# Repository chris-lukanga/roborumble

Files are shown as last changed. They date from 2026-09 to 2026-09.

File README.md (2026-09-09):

# Lightning McQueen 

**Team Name:** CO Coders
**Solution Name:** Lightning McQueen
**Category:** Robo Grand Prix (autonomous racing)
**Event:** Robo Rumble 2026 — Elimination Round

---

## What we are building

Lightning McQueen is an **autonomous line-following racer**. It reads the track
with a five-channel infrared reflective array, works out how far it is off the
line, and steers by commanding a **path curvature** rather than a raw motor
difference. The speed it runs at is then chosen from that curvature — flat out on
the straights, backed off exactly as much as the corner requires and no more.

There is no radio, no Wi-Fi and no Bluetooth anywhere on this vehicle. The only
human input is an ARM button pressed before the car is released, and the
emergency stop. That is a deliberate design decision, not an omission: Robo
Grand Prix requires full autonomy, and any human intervention forfeits the run.

**The strategy in one line:** most line followers lose time because they brake
for corners they have already entered. We compute the curvature the controller
is *about* to demand, and set the speed from that — so the car is already at the
right speed when the corner arrives.

---

## How we are building it

| Phase | Tool | Status |
|---|---|---|
| Control-law development | **Webots** (e-puck differential-drive model) | Complete — see `Folder B/Simulation` |
| Circuit design and MCU logic | **Wokwi** | Complete — see `Folder B/Schematics` |
| Mechanical design | **CadQuery** parametric CAD (OpenCASCADE kernel) | Complete — see `Folder B/Mechanical Design` |
| Physical build | Laser-cut acrylic deck, bolted assembly | Documented, not yet assembled |

Everything in this repository is reproducible. The CAD is a Python script, the
schematics are a Python script, the flowcharts are Mermaid source. Run them and
you get the same files back.

---

## Competition compliance

| Universal Design Constraint | How Lightning McQueen meets it |
|---|---|
| **1. Footprint ≤ 50 × 50 cm** | Overall envelope **300 × 211 × 107 mm**. The CAD build script asserts this on every run and fails loudly if a change ever breaks it. |
| **2. Mass < 5 kg** | Estimated **0.86 kg** fully assembled. Full mass budget in `Folder C/Holistic_Build_Document.md`. |
| **3. Accessible ON/OFF switch** | **SW2**, an SPST rocker at the rear-left corner of the deck, clear of the wheels and the sensor boom. Drawn and annotated in `Folder B/Schematics/01_power_safety_chain.svg`. |
| **4. Emergency Stop** | **SW1**, a 22 mm latching mushroom head on a 48 mm mast at the rear centreline. Wired **first** in the battery positive line, upstream of SW2 and of the H-bridge. Drawn and annotated in the same schematic and rendered in `Folder B/Mechanical Design/renders/04_safety_annotated.png`. |
| **Robo Grand Prix: fully autonomous** | No radio, no Wi-Fi, no Bluetooth, no serial command path. Serial is output-only telemetry. |

The 20 × 30 cm breadboard-on-plate layout from our original concept is carried
through: the 830-point breadboard sits on a 300 × 200 mm laser-cut acrylic deck
that also carries the Arduino, the H-bridge and the battery pack. Light materials
keep mass off the wheels; the batteries are the heaviest single item, which is
why we run **two 9 V PP3 cells** rather than twelve 1.5 V cells.

---

## Directory map

### [`Folder A — Source Code`](./Folder%20A)

Everything needed to run the build, plus the documentation of *how* the software
is put together.

| Path | Contents |
|---|---|
| `firmware/lightning_mcqueen/` | The race firmware. `lightning_mcqueen.ino` is the 200 Hz control superloop and five-state supervisor; `config.h` holds every tunable, each traceable to a datasheet, the CAD model, or a simulation sweep. |
| `firmware/calibration/` | A separate sketch that measures the sensor thresholds, the motor trim and the PWM deadband on the actual track, and prints the numbers to paste into `config.h`. |
| `simulation/` | The Webots C++ controller the control law was developed in. |
| `flowcharts/` | Five diagrams — system architecture, the control loop, the state machine, line-loss recovery, and the power/safety chain — as Mermaid source and rendered PNG. |
| `PROGRAMMING.md` | The programming methods, frameworks and architecture, with the flowcharts inline and the control law derived from first principles. |

### [`Folder B — Designs`](./Folder%20B)

The physical and electronic blueprints.

| Path | Contents |
|---|---|
| `Mechanical Design/` | `MECHANICAL_DESIGN.md` (fabrication method, fastening, mass budget), `CAD/` (the parametric model, STEP and STL for every part, a laser-cut DXF of the deck), `renders/` (five shaded views including the annotated safety view). |
| `Electronic Design/` | `ELECTRONIC_DESIGN.md` — why each sensor, driver and controller was chosen, with the alternatives we rejected and the reason. |
| `Schematics/` | `SCHEMATICS.md`, the full system schematic, and a dedicated power-and-safety-chain drawing with the ON/OFF switch and E-Stop explicitly annotated. Both are generated by `draw_schematics.py`. |
| `Simulation/` | `SIMULATION.md` — what we tested in Webots, what the sweeps told us, and which firmware constants came out of them. |

### [`Folder C — Documentation`](./Folder%20C)

| Path | Contents |
|---|---|
| `Pitch_Deck.pdf` | 7 slides: introduction, solution, technical approach, cost, team. |
| `Bill_of_Materials.xlsx` | Every component with quantity, unit cost, supplier, stock code and buy link. **Total cost is highlighted in red.** |
| `Holistic_Build_Document.md` | The full written report: constraints, solution, BOM summary, and the three required technical sub-sections (mechanical, electronic, programming). |
| `FQA_Attendance_Log.md` | Facilitator Q&A attendance logbook. |
| `FQA_Proof/` | Attendance screenshots referenced by the logbook. |

---

## Reproducing the design files

```bash
pip install cadquery schemdraw matplotlib numpy

# CAD: STEP + STL for every part, plus the laser-cut DXF
python3 "Folder B/Mechanical Design/CAD/lightning_mcqueen_cad.py"

# Renders: five shaded views
python3 "Folder B/Mechanical Design/CAD/render_views.py"

# Schematics: SVG + PNG
python3 "Folder B/Schematics/draw_schematics.py"
```

---

## Team

| Member | Role |
|---|---|
| *(see `Folder C/Pitch_Deck.pdf`, Team Slide)* | |

---

## Credits and attribution

- The Webots control law began from the standard e-puck line-following example
  distributed with Webots, and was rewritten around curvature control and a
  speed schedule. The original example's structure is acknowledged.
- The TCRT5000 sensing approach follows the device datasheet's recommended
  8–15 mm standoff.
- Everything else — the firmware, the CAD, the schematics and the documentation
  in this repository — is our own work.

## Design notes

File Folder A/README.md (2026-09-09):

# Folder A — Source Code

All programming scripts, firmware and code required to run Lightning McQueen,
plus the documentation of the programming methods, frameworks and design.

**Start here:** [`PROGRAMMING.md`](PROGRAMMING.md) — the frameworks we use, the
control law derived from first principles, and all five flowcharts.

| Path | What it is |
|---|---|
| [`PROGRAMMING.md`](PROGRAMMING.md) | Programming methods, frameworks, architecture and flowcharts |
| [`firmware/lightning_mcqueen/`](firmware/lightning_mcqueen) | The race firmware — 200 Hz control superloop and five-state supervisor |
| [`firmware/lightning_mcqueen/config.h`](firmware/lightning_mcqueen/config.h) | Every tunable in one place, each traceable to a datasheet, the CAD model or a simulation sweep |
| [`firmware/calibration/`](firmware/calibration) | Measures sensor thresholds, motor trim and PWM deadband on the real track |
| [`simulation/`](simulation) | The Webots C++ controller the control law was developed in |
| [`flowcharts/`](flowcharts) | Five diagrams as Mermaid source (`.mmd`) and rendered PNG |

## Building and flashing

```
Arduino IDE 2.x  →  Board: Arduino Uno  →  Port: your Uno
Open  firmware/lightning_mcqueen/lightning_mcqueen.ino  →  Upload
```

`config.h` must sit in the same folder as the `.ino` — the Arduino IDE requires
the sketch folder name to match the sketch name, which is why the structure
looks the way it does.

**Order of operations on a new car:**

1. Flash `firmware/calibration/calibration.ino`.
2. Send `1` over serial at 115200 and sweep the car across the line for 10 s.
   Paste the printed `SENSOR_MIN[]` / `SENSOR_MAX[]` arrays into `config.h`.
3. Send `3` and note the duty at which each wheel first turns. That is
   `PWM_DEADBAND`.
4. Send `2` and measure the travel of each wheel. That ratio is `TRIM_RIGHT`.
5. Flash `firmware/lightning_mcqueen/lightning_mcqueen.ino`.

## Category alignment

This is autonomous racing code and nothing else. No radio, no Wi-Fi, no
Bluetooth, no serial command path — `Serial` is written to and never read. The
only human input is the ARM button pressed before the car is released.

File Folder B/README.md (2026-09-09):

# Folder B — Designs

The physical and electronic blueprints for Lightning McQueen.

| Subfolder | Start here | Contents |
|---|---|---|
| [`Mechanical Design/`](Mechanical%20Design) | [`MECHANICAL_DESIGN.md`](Mechanical%20Design/MECHANICAL_DESIGN.md) | Fabrication method, fastening scheme, mass budget, parametric CAD (STEP/STL/DXF) and five shaded renders |
| [`Electronic Design/`](Electronic%20Design) | [`ELECTRONIC_DESIGN.md`](Electronic%20Design/ELECTRONIC_DESIGN.md) | Justification for every sensor, driver and control unit, with the alternatives we rejected and why |
| [`Schematics/`](Schematics) | [`SCHEMATICS.md`](Schematics/SCHEMATICS.md) | Full system schematic plus a dedicated power-and-safety-chain drawing with the ON/OFF switch and E-Stop annotated |
| [`Simulation/`](Simulation) | [`SIMULATION.md`](Simulation/SIMULATION.md) | What we tested in Webots, what the sweeps told us, which constants came out of them, and what simulation could not tell us |

## Safety compliance at a glance

| Constraint | Where it is drawn | Where it is rendered |
|---|---|---|
| **3 — accessible ON/OFF switch** | [`Schematics/01_power_safety_chain.svg`](Schematics/01_power_safety_chain.svg) — SW2, annotated | [`Mechanical Design/renders/04_safety_annotated.png`](Mechanical%20Design/renders/04_safety_annotated.png) |
| **4 — Emergency Stop** | [`Schematics/01_power_safety_chain.svg`](Schematics/01_power_safety_chain.svg) — SW1, annotated, first in the battery positive line | [`Mechanical Design/renders/04_safety_annotated.png`](Mechanical%20Design/renders/04_safety_annotated.png) |

## Everything here is reproducible

```bash
pip install cadquery schemdraw matplotlib numpy

python3 "Mechanical Design/CAD/lightning_mcqueen_cad.py"   # STEP, STL, DXF
python3 "Mechanical Design/CAD/render_views.py"            # the five renders
python3 "Schematics/draw_schematics.py"                    # both schematics
```

The CAD build script asserts the 50 × 50 cm footprint rule on every run and
fails loudly if a parameter change ever breaks it.

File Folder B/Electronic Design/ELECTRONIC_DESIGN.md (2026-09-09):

# Electronic Design

**Team CO Coders · Lightning McQueen · Robo Rumble 2026 · Robo Grand Prix**

This document justifies every active component on the vehicle. For each one we
state what it does, why it was chosen, and what we rejected instead. The wiring
itself is in [`../Schematics`](../Schematics).

---

## 1. Control unit — Arduino Uno R3 (ATmega328P)

**Role.** Reads five analog channels, runs the control law at 200 Hz, drives six
pins into the H-bridge.

**Why.** The job is small and the requirements are specific: at least five ADC
channels, two independent hardware PWM timers, and enough determinism to trust a
5 ms loop. The ATmega328P has six ADC channels and three timers, and its
successive-approximation ADC converts in 104 µs. Five conversions cost 520 µs —
10 % of the control period. The whole pipeline measures ~760 µs, so we run at
15 % CPU with 85 % headroom.

**Why not an ESP32.** It is faster, it has more ADC resolution, and we
considered it seriously. Two things ruled it out. First, its ADC is
non-linear near the rails and needs per-channel characterisation to be trusted —
extra work for a signal we are already normalising. Second, and decisively, it
arrives with Wi-Fi and Bluetooth radios on the die. Robo Grand Prix forbids
remote control of any kind. We would rather hand a judge a board that
*physically cannot* be commanded remotely than a board where the argument
depends on firmware we claim we did not write.

**Why not a bare ATmega328P on the breadboard.** It saves 15 g and R120, and
costs an afternoon of bootloader and crystal work at the point in the schedule
where we can least afford it.

**Pin map and the one non-obvious decision.**

| Function | Pin | Note |
|---|---|---|
| Sensor channels 1–5 | A0–A4 | A5 left free for a future encoder or I²C |
| Motor A direction | D2, D4 | plain digital |
| Motor A speed | **D9** | Timer1 |
| Motor B direction | D7, D8 | plain digital |
| Motor B speed | **D10** | Timer1 |
| ARM button | D12 | `INPUT_PULLUP`, active low |
| Status LED | D13 | on-board LED doubles as the status light |
| Buzzer | D3 | Timer2 via `tone()` |

The PWM pins are on **Timer1 (D9, D10), not Timer0 (D5, D6)**. Timer0 drives
`millis()` and `micros()`, which the fixed-rate scheduler depends on. Sharing it
with motor PWM is the kind of coupling that produces a bug you only see at one
particular duty cycle, three days before the event.

---

## 2. Motor driver — L298N dual H-bridge module

**Role.** Takes 9 V from the switched battery rail and six logic lines from the
Uno, and drives two motors bidirectionally. Its on-board 78M05 also generates
the 5 V logic rail.

**Why.** It handles 2 A per channel against a stall current of roughly 1.2 A per
TT motor, so there is real margin. The module carries flyback diodes and the
regulator already, which removes a whole subcircuit from the breadboard — and a
breadboard is exactly where a hand-wired flyback diode goes intermittent.

**The honest downside.** The L298 is a bipolar bridge and drops roughly 1.9 V
across itself. From a 9 V pack, the motors see about 7.1 V, and the wheels do
not turn at all below about 16 % duty. We handle this in two places:

- `PWM_DEADBAND = 42` in `config.h` maps the controller's 0–1 output onto duty
  42–255, so a small correction actually produces movement instead of only
  heating the bridge;
- the calibration sketch (mode 3) measures the real deadband on the actual
  motors, because it varies between gearboxes.

**Why not a TB6612FNG.** It is a MOSFET bridge, drops ~0.5 V instead of 1.9 V,
and is genuinely the better part — we would gain roughly 18 % top speed. It was
rejected on availability and cost risk: the L298N is stocked by every South
African hobby supplier and costs a third as much. If a TB6612FNG is in hand
before the build, it is a drop-in swap: same six control lines, same pin map,
and only `PWM_DEADBAND` and `MAX_WHEEL_RPM` change.

---

## 3. Sensing — 5-channel TCRT5000 reflective array

**Role.** Measures how far the car is off the line.

**Why this sensor.** The TCRT5000 is an IR emitter and phototransistor in one
package with a daylight-blocking filter over the detector. Its datasheet optimum
standoff is 8–15 mm; we mount at 12 mm, in the middle of that band, so ±3 mm of
deck deflection or track unevenness does not move us out of it.

**Why five channels and not three.** This is the single most consequential
electronic decision on the car.

Three binary sensors can only report five distinct error values:
{−1, −0.5, 0, +0.5, +1}. That is what our Webots prototype had, and the
quantisation is why its derivative term needed such heavy filtering — every
transition was a step change. Five **analog** channels let us compute a weighted
centroid, which is continuous. Continuous error means:

- the derivative term is usable, so the car damps its own oscillation instead of
  weaving down the straights;
- the speed schedule sees corner entry developing gradually rather than as a
  step, so it sheds speed smoothly instead of lurching;
- a 40 mm sensing span at 20 mm pitch straddles a 19 mm competition line with a
  channel to spare on each side, so a moderate excursion is still measured
  rather than simply "lost".

The cost of the two extra channels is about R40 and two ADC pins we had spare.

**Per-channel calibration.** The five devices differ measurably in LED output
and phototransistor gain. `config.h` therefore stores `SENSOR_MIN[]` and
`SENSOR_MAX[]` per channel rather than one global threshold, and
`calibration.ino` mode 1 measures them on the actual track under the actual
lighting. It also warns if any channel shows less than 350 counts of
floor-to-line contrast, which is the signal that the ride height or the trim pot
is wrong — better to find that in the pit than on the grid.

---

## 4. Power — 2 × 9 V PP3

**Role.** One switched 9 V rail feeding the H-bridge, from which the 78M05
derives 5 V logic.

**Why 9 V PP3 and not AA cells.** Our concept notes committed to this and the
mass budget vindicates it: two PP3 cells weigh 92 g where twelve 1.5 V AA cells
weigh about 276 g. On a car whose whole assembled mass is 855 g, that is a
21 % difference in the load the same TT gearboxes have to accelerate.

**The honest downside.** A PP3 alkaline has roughly 550 mAh and a fairly high
internal resistance. Two in series-parallel give us about 1.2 Ah at 9 V, which is
comfortable for a race heat but not for an afternoon of testing — and under a
stall the terminal voltage sags enough to matter. Mitigations:

- the polyfuse and the wiring are sized for the sag, not the nominal;
- `TRIM_RIGHT` and the speed schedule are calibrated on a fresh pack, and the
  pack is swapped between heats (hook-and-loop straps, ten seconds);
- for bench testing we run from a 9 V bench supply, not from cells.

**Single rail, not two.** Some designs run separate logic and motor batteries so
that motor sag cannot brown out the MCU. We deliberately do not, because a
separate logic battery would keep the MCU alive after the E-Stop opens the motor
rail. A shared rail means one switch kills everything — which is exactly what
Universal Design Constraint 4 asks for. The trade is a 100 µF bulk capacitor on
the 5 V rail to ride out switching transients.

---

## 5. Protection and indication

| Part | Value | Why |
|---|---|---|
| **F1** polyfuse | 2 A hold | Against a stalled motor or a wiring short. Resettable, so a pit incident does not consume a spare. Sized above the 1.2 A per-motor stall so it does not nuisance-trip on a hard corner. |
| **D1** power LED | + 1 kΩ | Shows the rail is live. On a car whose normal state is "sitting still, waiting", this is the difference between a safe approach and an assumed-dead robot. |
| **D2** status LED | on-board D13, 220 Ω | Blink codes state: slow = disarmed, fast = armed countdown, solid = racing, urgent = fault. Readable from the side of the track. |
| **LS1** piezo | on D3 | Audible arm, countdown and fault. A marshal facing away still hears the fault tone. |
| **C1** bulk cap | 100 µF on the 5 V rail | Rides out H-bridge switching transients. Deliberately no larger — see the safety note below. |

**A note on that capacitor.** 100 µF at 5 V stores 1.25 mJ. A loaded TT gearbox
needs on the order of a joule to turn once. There is no combination of
downstream capacitance on this vehicle that could move a wheel after the E-Stop
opens, and that is a design constraint we checked rather than assumed.

---

## 6. Safety devices — Universal Design Constraints 3 and 4

Detailed in [`../Schematics/SCHEMATICS.md`](../Schematics/SCHEMATICS.md) and
drawn in `../Schematics/01_power_safety_chain.svg`. In summary:

- **SW1, E-Stop:** 22 mm latching mushroom, normally closed, **first device in
  the battery positive line**, upstream of SW2 and of the L298N.
- **SW2, ON/OFF:** SPST rocker, second in the same line.

Because the 5 V logic rail is derived downstream of both, opening either one
de-energises the MCU, the sensor array and the motors together. No firmware path
can defeat SW1, because the contact is mechanically in the battery line.

---

## 7. Component summary

| Ref | Component | Qty | Function |
|---|---|---:|---|
| U1 | L298N dual H-bridge module | 1 | Motor drive + 5 V regulation |
| U2 | Arduino Uno R3 | 1 | Control |
| U3 | 5-channel TCRT5000 array | 1 | Line sensing |
| M1, M2 | TT gear motor 1:48 + 65 mm wheel | 2 | Drive |
| BT1, BT2 | 9 V PP3 + holder | 2 | Power |
| SW1 | 22 mm latching E-Stop, NC | 1 | **Emergency stop (Constraint 4)** |
| SW2 | SPST rocker switch | 1 | **ON/OFF (Constraint 3)** |
| SW3 | Momentary pushbutton | 1 | ARM |
| F1 | 2 A resettable polyfuse | 1 | Overcurrent protection |
| D1 | 5 mm LED + 1 kΩ | 1 | Power-on indication |
| D2 | Status LED + 220 Ω | 1 | State indication |
| LS1 | Piezo buzzer | 1 | Audible state |
| C1 | 100 µF electrolytic | 1 | 5 V rail bulk |
| — | 830-point breadboard | 1 | Interconnect |
| — | Ball castor, 20 mm | 1 | Tail support |

Costs, suppliers, stock codes and buy links are in
[`../../Folder C/Bill_of_Materials.xlsx`](../../Folder%20C/Bill_of_Materials.xlsx).

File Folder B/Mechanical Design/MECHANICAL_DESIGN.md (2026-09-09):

# Mechanical Design

**Team CO Coders · Lightning McQueen · Robo Rumble 2026 · Robo Grand Prix**

---

## 1. The design at a glance

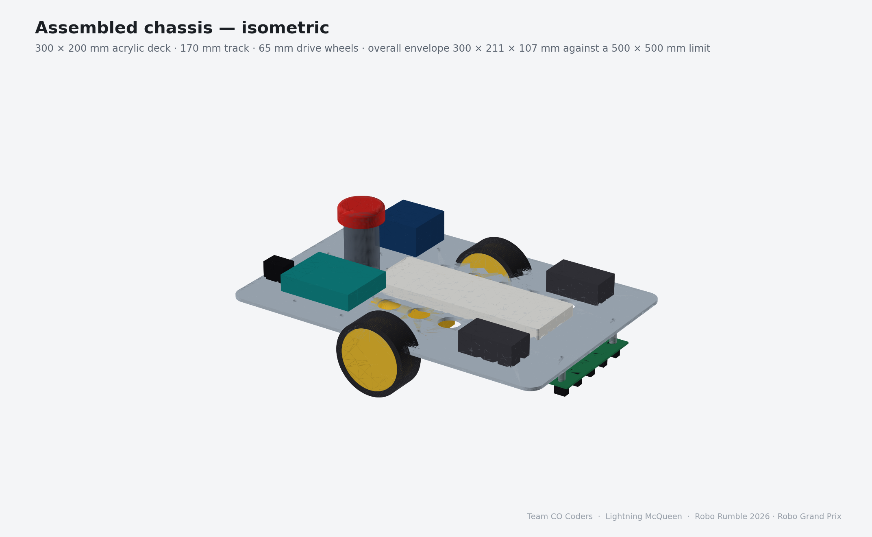
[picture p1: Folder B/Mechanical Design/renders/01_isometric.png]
Assembled chassis


A single 3 mm laser-cut acrylic deck, 300 × 200 mm, carrying everything. The
830-point breadboard sits on top on the centreline; the Arduino and the L298N
flank it; the battery pack sits forward. Two TT gear motors bolt through the
deck from below at mid-wheelbase, a ball castor supports the tail, and the
sensor boom hangs off the nose on nylon standoffs.

| | |
|---|---|
| Overall envelope | **300 × 211 × 107 mm** (limit: 500 × 500 mm) |
| Deck | 300 × 200 × 3 mm cast acrylic |
| Track (wheel centres) | 170 mm |
| Wheelbase (axle to castor) | 118 mm |
| Ground clearance under the deck | 42 mm |
| Sensor ride height | 12 mm above the floor |
| Sensor lead ahead of the drive axle | 138 mm |
| Estimated assembled mass | **0.86 kg** (limit: below 5 kg) |

The width comes out at 211 mm rather than 200 mm because the wheels sit 5.5 mm
proud of the deck on each side. That is intentional: it keeps the tyres clear of
the deck edge so a brush against a barrier hits rubber, not acrylic.

---

## 2. Fabrication method

**The deck is laser cut, not drilled.** `CAD/deck_plate_laser_cut.dxf` is a 1:1
flat profile containing the outline, all 34 M3 clearance holes, the 22.5 mm
E-Stop bore, the lightening holes and the two cable slots. It goes to the cutter
as-is. Nothing on this vehicle is marked out and drilled by hand, because
hand-drilled acrylic chips and hand-marked hole patterns do not repeat.

| Part | Method | Material |
|---|---|---|
| Deck plate | Laser cut from the supplied DXF | 3 mm cast acrylic |
| E-Stop mast | 3D printed, 30 mm dia × 48 mm, 4 perimeters, 40 % infill | PLA |
| Sensor boom standoffs | Off-the-shelf | M3 × 30 mm nylon hex standoffs |
| Deck module standoffs | Off-the-shelf | M3 × 8 mm nylon hex standoffs |
| Motor brackets | Off-the-shelf, supplied with the TT motors | ABS |
| Fasteners throughout | Off-the-shelf | M3 × 10 mm pan-head, nyloc nuts |

**Why acrylic rather than 3D printing the whole chassis.** A printed monocoque
looks better in renders, but a 300 mm printed part warps, takes eight hours, and
cannot be re-cut in an afternoon when a mounting hole turns out to be 4 mm out.
A laser-cut flat plate takes ninety seconds on the machine and is dimensionally
exact. For a competition where the schedule is the real constraint, that matters
more than the aesthetics.

**Why 3 mm and not 5 mm.** 3 mm cast acrylic spanning 300 mm with the load
concentrated at the motor mounts deflects about 0.4 mm at the nose under the
assembled mass — well inside the ±2 mm the sensor ride height tolerates. Going to
5 mm would add 240 g for stiffness we do not need.

---

## 3. Fastening and assembly

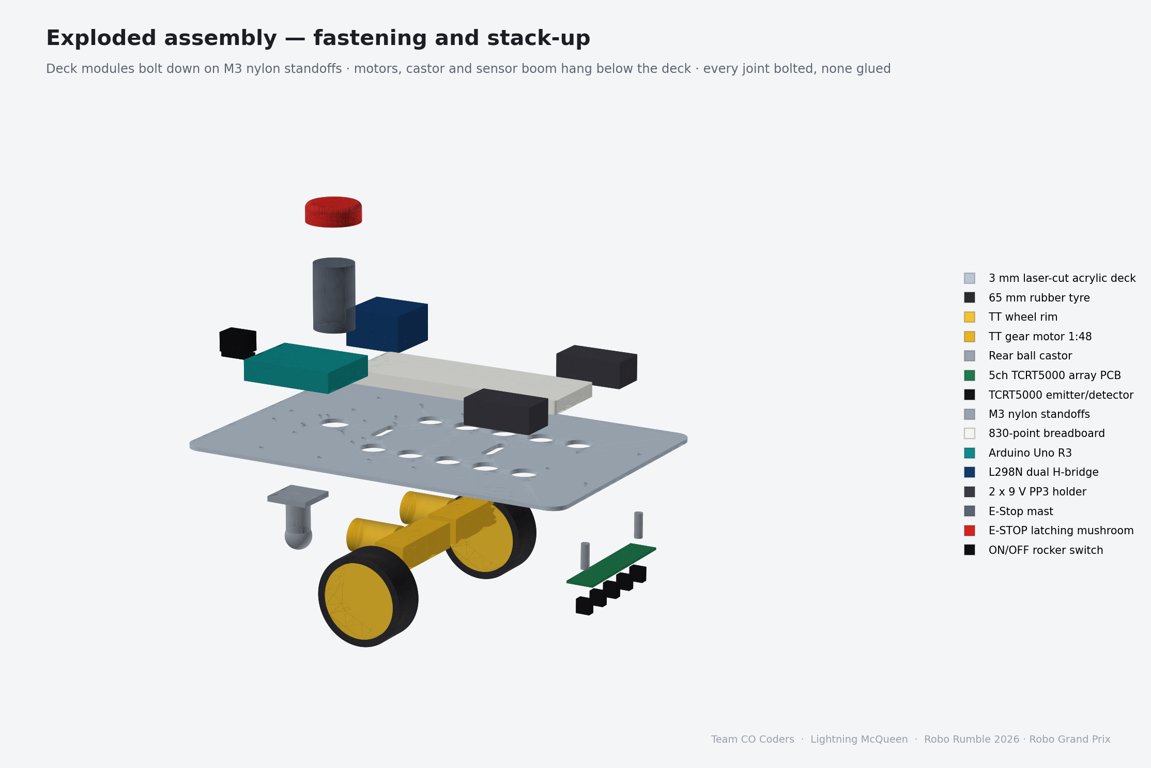
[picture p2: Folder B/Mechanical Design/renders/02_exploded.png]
Exploded assembly


**Every joint on this vehicle is bolted. Nothing is glued.** Adhesive joints in
acrylic are brittle, they cannot be adjusted, and when a sensor turns out to be
2 mm too low there is no way back. Bolted joints come apart.

The stack-up, from the ground up:

1. **Wheels** press onto the TT motor D-shafts.
2. **TT motors** bolt to the underside of the deck through the ABS brackets,
   two M3 per side, at X = 150 mm from the tail.
3. **Ball castor** bolts to the underside at the tail on a 24 mm square M3
   pattern.
4. **Sensor boom** hangs on two M3 × 30 mm nylon standoffs at X = 288 mm,
   ±40 mm either side of the centreline. Nylon, not steel, because the standoffs
   sit directly beside the IR emitters and a steel post reflects.
5. **Breadboard** sits on the deck centreline on 8 mm standoffs, four M3.
6. **Arduino Uno** and **L298N** bolt down on 8 mm standoffs on either flank,
   four M3 each.
7. **Battery holders** are strapped forward with hook-and-loop, so a flat pack
   is a ten-second swap between heats rather than an unbolting job.
8. **E-Stop mast** bolts down on a 4 × M3 circle on a 22 mm radius, over the
   22.5 mm bore that passes the button body through the deck.

### Adjustment designed in

- **Sensor ride height** is set by the standoff length. If the track surface
  reads badly at 12 mm, an M3 × 25 or M3 × 35 standoff moves it without
  re-cutting anything.
- **Weight distribution** is set by where the battery straps sit. Moving the
  pack rearward shifts load onto the drive wheels for grip; forward reduces
  castor scrub.
- **Motor position** is fixed. This is the one dimension we do not want anyone
  adjusting between heats — it sets the sensor lead, which the speed schedule
  depends on.

---

## 4. Underside — drivetrain and sensing

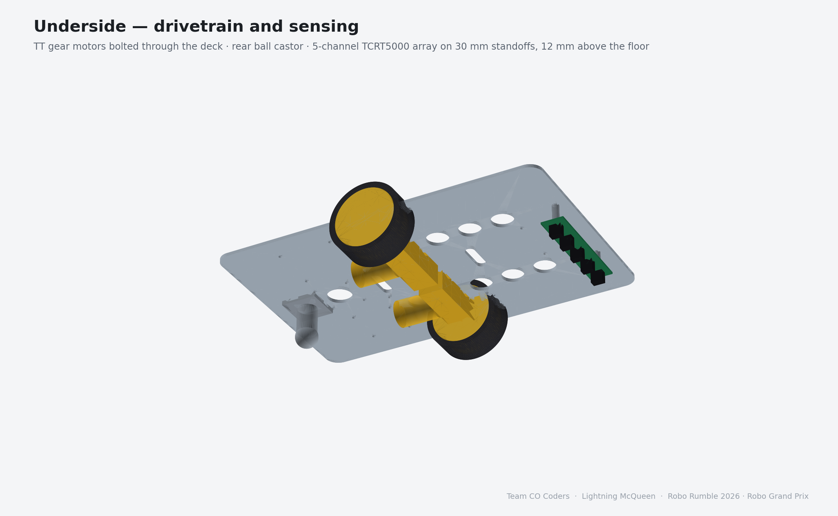
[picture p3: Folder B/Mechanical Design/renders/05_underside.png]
Underside


The two TT gearboxes point inboard from the wheels and very nearly meet on the
centreline, which is the standard dual-TT arrangement and keeps the mass low and
central. The castor carries perhaps 15 % of the mass; the rest sits over the
drive wheels, which is where it is useful.

The sensor boom is the part most likely to be damaged, so it is the part that is
easiest to replace: two standoffs, two bolts, and it is off.

---

## 5. Safety hardware — Universal Design Constraints 3 and 4

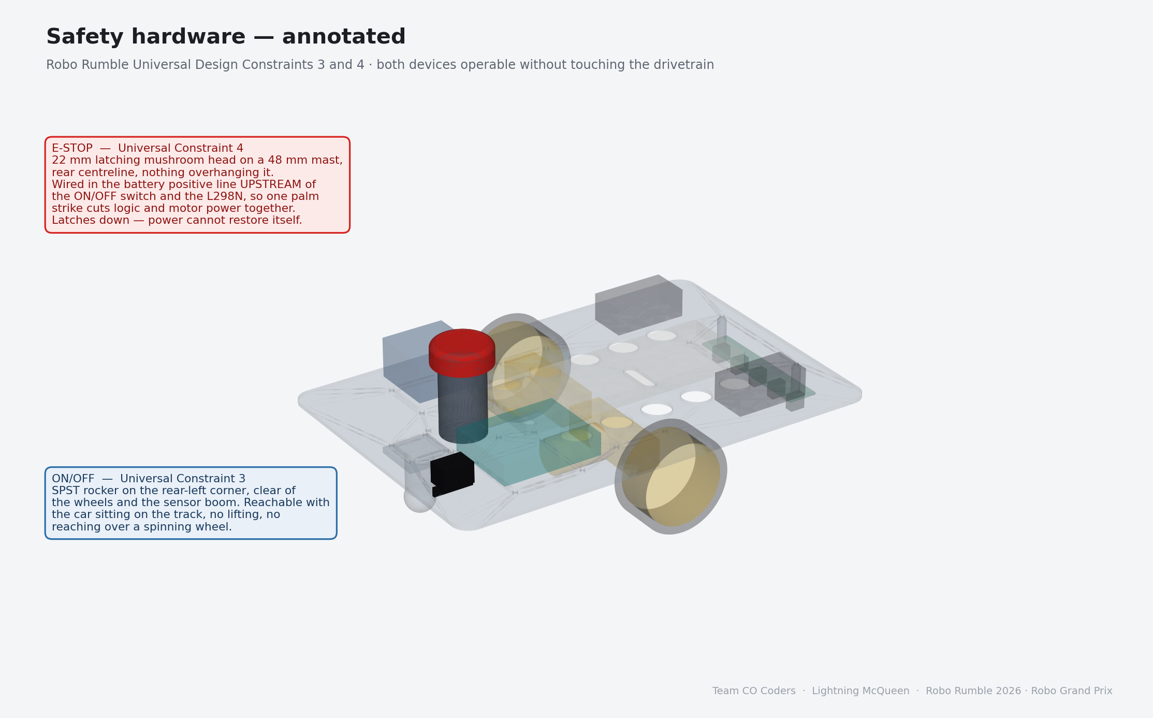
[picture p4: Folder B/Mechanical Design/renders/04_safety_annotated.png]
Safety hardware annotated


**E-Stop (Constraint 4).** A 22 mm latching mushroom head on a 48 mm printed
mast at the rear centreline. It is the tallest object on the car and nothing
overhangs it, so it can be struck from above or from behind with an open palm
while the car is moving. It latches down: power cannot restore itself until an
operator twists the head back out. Electrically it is the *first* device in the
battery positive line — see `../Schematics/01_power_safety_chain.svg`.

**ON/OFF (Constraint 3).** An SPST rocker at the rear-left corner of the deck,
clear of the wheels and of the sensor boom. It is operable with the car sitting
on the grid — no lifting, no tilting, and no reaching across a wheel that is
about to spin.

Both are at the rear because that is the end an operator approaches from. The
E-Stop is on the centreline and raised; the ON/OFF is in the corner and flush.
They are not confusable by feel.

---

## 6. Orthographic views

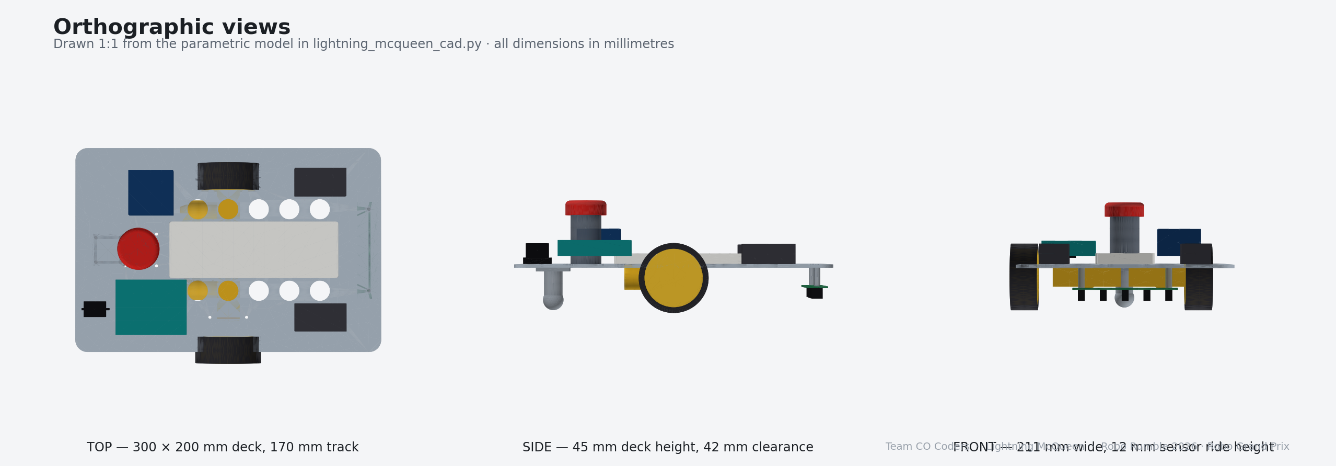
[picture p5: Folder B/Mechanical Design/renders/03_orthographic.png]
Orthographic views


Drawn 1:1 from the parametric model.

---

## 7. Mass budget

| Item | Qty | Unit (g) | Total (g) |
|---|---:|---:|---:|
| 3 mm acrylic deck, 300 × 200 mm, holed | 1 | 198 | 198 |
| TT gear motor 1:48 | 2 | 30 | 60 |
| 65 mm wheel | 2 | 30 | 60 |
| Ball castor assembly | 1 | 28 | 28 |
| Arduino Uno R3 | 1 | 25 | 25 |
| L298N module | 1 | 30 | 30 |
| 830-point breadboard | 1 | 90 | 90 |
| 5-channel TCRT5000 array | 1 | 12 | 12 |
| 9 V PP3 alkaline | 2 | 46 | 92 |
| Battery holders and straps | 2 | 14 | 28 |
| E-Stop button + printed mast | 1 | 62 | 62 |
| Rocker switch, fuse, LEDs, buzzer | — | — | 22 |
| Standoffs, bolts, nuts (≈60 pieces) | — | — | 68 |
| Wiring loom | — | — | 80 |
| **Total** | | | **855 g** |

**0.86 kg against a 5 kg limit.** We are at 17 % of the allowance, which is the
point of the light-material approach: less mass on the wheels means the same TT
gearboxes accelerate harder and the same tyres hold a tighter corner. The
batteries are the heaviest single line item at 92 g, which is exactly why two
9 V PP3 cells were chosen over twelve 1.5 V AA cells (≈276 g).

---

## 8. Files in this folder

```
Mechanical Design/
├── MECHANICAL_DESIGN.md              this document
├── CAD/
│   ├── lightning_mcqueen_cad.py      the parametric model — edit the
│   │                                 PARAMETERS block and re-run
│   ├── render_views.py               generates everything in renders/
│   ├── deck_plate_laser_cut.dxf      1:1 flat profile for the laser cutter
│   ├── lightning_mcqueen_assembly.step   full coloured assembly
│   ├── STEP/                         one .step per part (Fusion / SolidWorks)
│   └── STL/                          one .stl per part (printing, meshing)
└── renders/
    ├── 01_isometric.png
    ├── 02_exploded.png
    ├── 03_orthographic.png
    ├── 04_safety_annotated.png
    └── 05_underside.png
```

The model is parametric. Changing `TRACK` or `WHEEL_D` at the top of
`lightning_mcqueen_cad.py` and re-running regenerates every STEP, STL, the DXF
and all five renders consistently. The build script also asserts the 50 × 50 cm
footprint rule on every run and fails loudly if a change ever breaks it.

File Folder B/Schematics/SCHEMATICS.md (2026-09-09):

# Schematics

**Team CO Coders · Lightning McQueen · Robo Rumble 2026 · Robo Grand Prix**

Two drawings. The first is the safety-critical power path on its own, because
Universal Design Constraints 3 and 4 deserve a drawing where nothing competes
for attention. The second is the complete system.

Both are generated by `draw_schematics.py` — run it and you get identical files
back. SVG is the master; PNG is provided for the pitch deck and for readers
without an SVG viewer.

---

## 1. Power and safety chain — Constraints 3 and 4

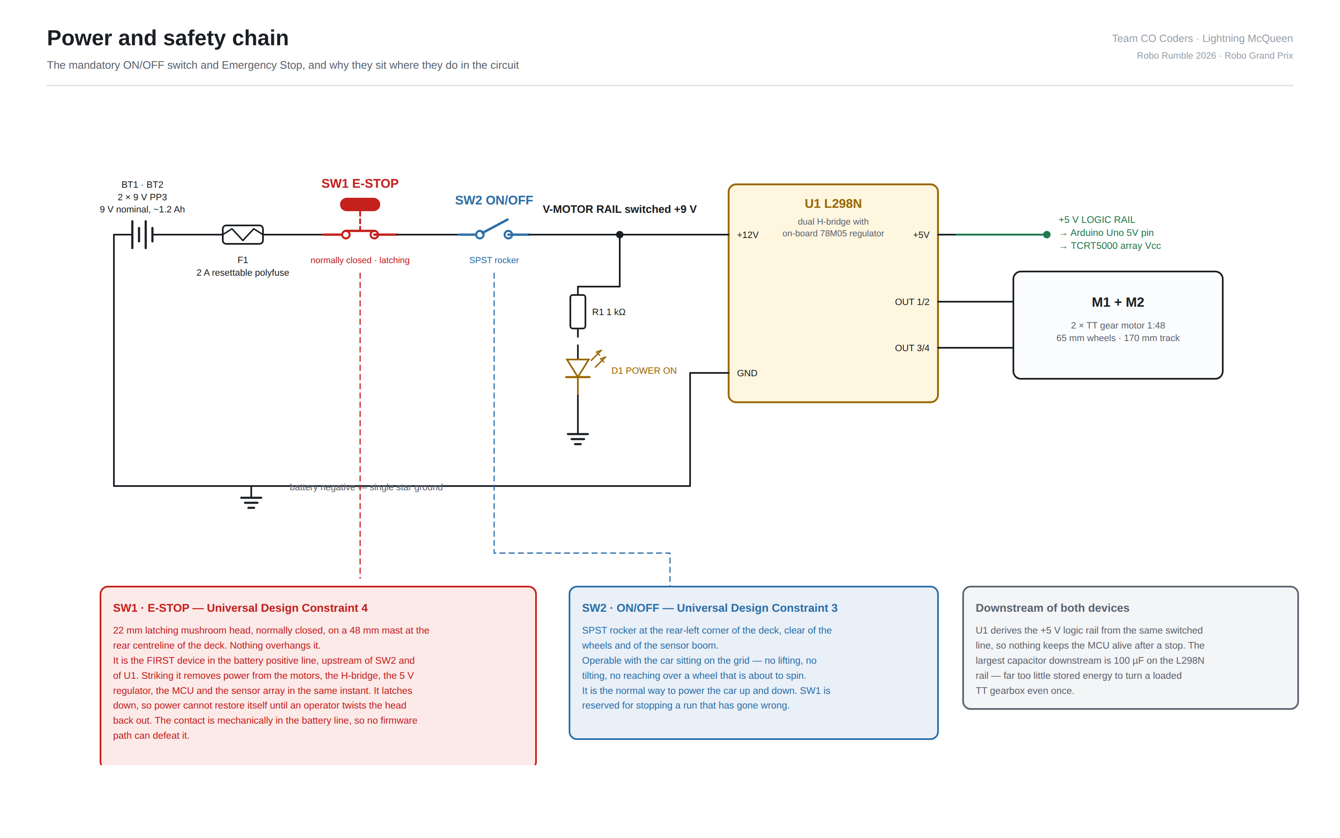
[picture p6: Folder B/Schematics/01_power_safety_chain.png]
Power and safety chain


### The chain, in order

```
BT1/BT2  →  F1  →  SW1 (E-STOP)  →  SW2 (ON/OFF)  →  U1 (L298N)  →  motors
2 × 9 V     2 A     latching NC       SPST rocker      +12V           M1, M2
                                                          ↓
                                                   78M05 → +5 V rail
                                                          ↓
                                              Arduino Uno · TCRT5000 array
```

### SW1 — Emergency Stop (Universal Design Constraint 4)

| | |
|---|---|
| Device | 22 mm latching mushroom-head pushbutton, **normally closed** |
| Location | Rear centreline of the deck, on a 48 mm mast — the tallest object on the car, nothing overhanging it |
| Position in circuit | **First device in the battery positive line**, upstream of SW2 and of U1 |
| Action | Struck from above or behind with an open palm. Latches down. |
| Reset | Twist the head to release — cannot restore itself |

**Why it is placed first.** Everything on this vehicle draws from one switched
rail. U1's on-board 78M05 derives the 5 V logic supply from the same line that
feeds the motors, so opening SW1 removes power from the motors, the H-bridge,
the regulator, the MCU and the sensor array **in the same instant**. There is no
sequencing, no software involvement and no state to unwind.

**Why it cannot be defeated.** The contact is mechanically in series with the
battery. No firmware path can bridge it, because there is no firmware left
running once it opens.

**Why residual energy is not a hazard.** The largest capacitor downstream is the
100 µF bulk cap on the 5 V rail, storing 1.25 mJ. Turning a loaded TT gearbox
through one revolution needs on the order of a joule — roughly a thousand times
more. The car cannot creep after a stop.

### SW2 — ON/OFF (Universal Design Constraint 3)

| | |
|---|---|
| Device | SPST rocker |
| Location | Rear-left corner of the deck, clear of the wheels and of the sensor boom |
| Position in circuit | Second in the battery positive line, immediately after SW1 |
| Access | Operable with the car sitting on the grid — no lifting, no tilting, no reaching across a wheel |

SW2 is the normal way to power the car up and down. SW1 is reserved for stopping
a run that has gone wrong. Placing them both at the rear — the end an operator
approaches from — with the E-Stop raised on the centreline and the rocker flush
in the corner means they are not confusable by feel.

---

## 2. Full system schematic

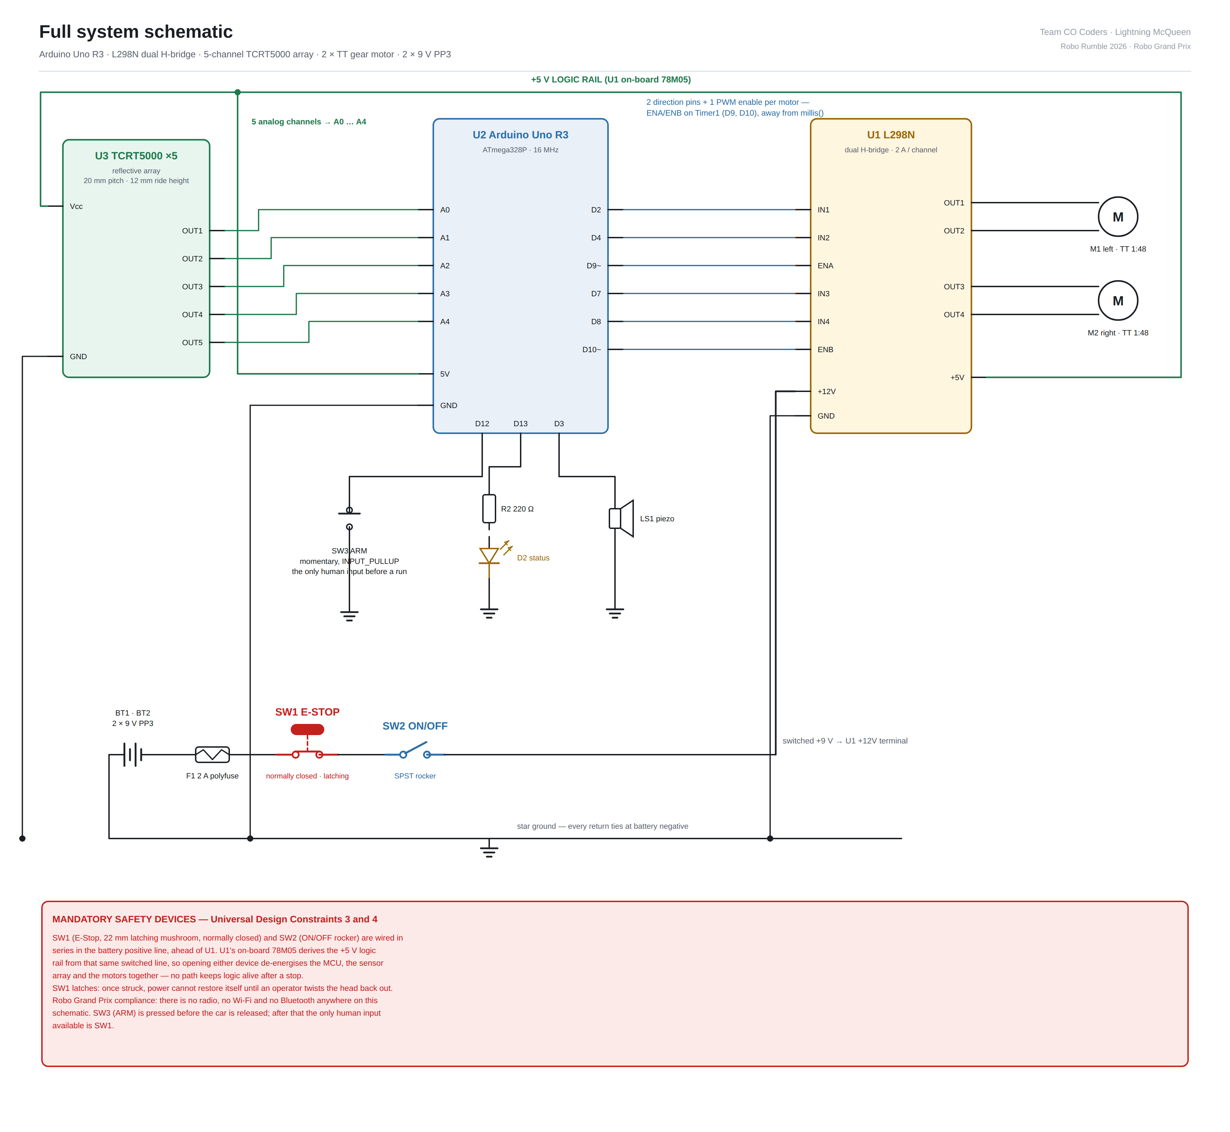
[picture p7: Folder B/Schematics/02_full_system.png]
Full system schematic


### Wiring table

| From | To | Signal |
|---|---|---|
| U3 OUT1 … OUT5 | U2 A0 … A4 | 5 analog sensor channels |
| U2 D2, D4 | U1 IN1, IN2 | Motor A direction |
| U2 D9 (Timer1) | U1 ENA | Motor A PWM |
| U2 D7, D8 | U1 IN3, IN4 | Motor B direction |
| U2 D10 (Timer1) | U1 ENB | Motor B PWM |
| U1 OUT1, OUT2 | M1 | Left motor |
| U1 OUT3, OUT4 | M2 | Right motor |
| U1 +5V | U2 5V, U3 Vcc | Derived logic rail |
| U2 D12 | SW3 → GND | ARM button, `INPUT_PULLUP` |
| U2 D13 | R2 220 Ω → D2 → GND | Status LED |
| U2 D3 | LS1 → GND | Piezo buzzer |
| BT1/BT2 + | F1 → SW1 → SW2 → U1 +12V | Switched battery positive |
| All GND | U1 GND pad | Star ground to battery negative |

### Grounding

Single star point at the L298N GND pad, which is the only tie to battery
negative. The sensor array, the Uno and the H-bridge each return there
independently rather than daisy-chaining, so motor current does not share a
conductor with the analog sensor return. On a car where the measurement is an
ADC reading of a phototransistor and the load is a pair of brushed motors, that
separation is what keeps the line position from wobbling every time the motors
change duty.

### Robo Grand Prix compliance, visible on the drawing

There is no radio, no Wi-Fi module, no Bluetooth module and no receiver anywhere
on this schematic. The only human-operable devices are SW1 (E-Stop), SW2
(ON/OFF) and SW3 (ARM, pressed before the car is released). Serial is used for
telemetry out and is never read.

---

## 3. Files

```
Schematics/
├── SCHEMATICS.md                  this document
├── draw_schematics.py             generates both drawings
├── 01_power_safety_chain.svg/.png Constraints 3 and 4, annotated
└── 02_full_system.svg/.png        complete wiring
```

Regenerate with:

```bash
pip install matplotlib          # not required for the SVG, only for the raster fallback
python3 draw_schematics.py
```

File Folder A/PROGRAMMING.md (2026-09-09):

# Folder A — Programming methods, frameworks and design

**Team CO Coders · Lightning McQueen · Robo Rumble 2026 · Robo Grand Prix**

This document states the programming methods and frameworks we use, derives the
control law, and presents the flowcharts. The code it describes lives in
`firmware/` and `simulation/`.

---

## 1. Framework and toolchain

| Layer | Choice | Why |
|---|---|---|
| Target | **Arduino Uno R3 (ATmega328P, 16 MHz)** | 8-bit AVR with a hardware ADC on 6 channels and two independent 8-bit PWM timers. Enough for a 200 Hz loop with 90 % headroom, and universally available in South Africa. |
| Language | **C++ (Arduino core)** | No RTOS, no dynamic allocation, no `String`. The whole program is statically sized and there is no heap to fragment mid-race. |
| Structure | **Non-blocking fixed-rate superloop + finite state machine** | Deterministic period, no `delay()` anywhere in the race path, and a supervisor that can only be in one of five well-defined states. |
| Simulation | **Webots 2023b**, e-puck differential-drive model, C++ controller API | Lets us tune a control law against real differential-drive kinematics before any hardware exists. |
| Circuit | **Wokwi** | Validates the pin map and the H-bridge logic without magic smoke. |

**Deliberate non-choices.** No PID library — we need the integral clamped and
frozen during line loss, which the common libraries do not expose. No
`AccelStepper`/`Servo` — these are DC gearmotors. No FreeRTOS — a 5 ms
superloop with one job does not need a scheduler, and a scheduler would add
jitter we cannot measure on an Uno.

---

## 2. System architecture

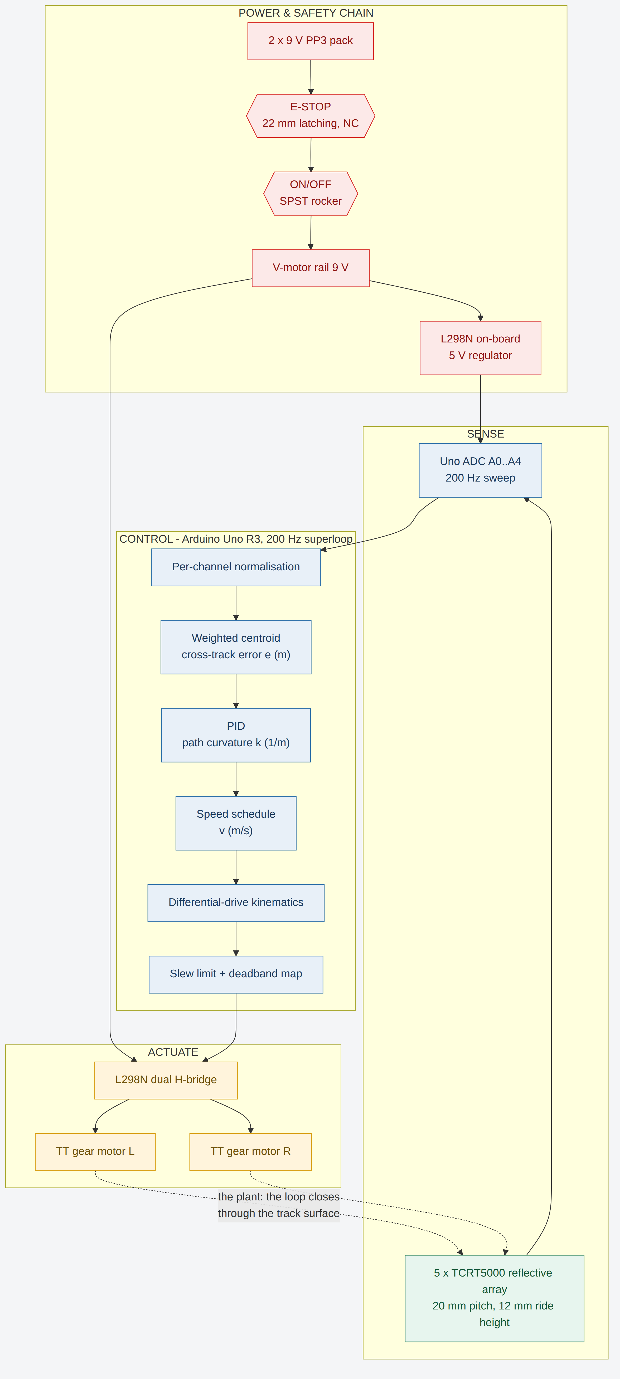
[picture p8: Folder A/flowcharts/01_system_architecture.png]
System architecture


The loop closes through the track surface: the motors move the car, the car
moves the sensor bar, the sensor bar reports a new error. Everything between is
software.

---

## 3. The control law, derived

### 3.1 Why curvature and not "PWM difference"

The naive line follower computes an error and adds it to one motor's PWM and
subtracts it from the other. That works, but the gain that feels right at low
speed oversteers at high speed, because the same PWM difference produces a much
tighter turn when the car is moving slowly and a much wider one when it is
moving fast. You end up tuning one set of gains per speed.

We instead have the PID output a **path curvature** κ, in units of 1/m. κ is a
property of the *path*, not of the throttle: κ = 1/R where R is the turn radius.
For a differential-drive vehicle with wheel separation *b*:

```
v_left  = v · (1 − κ·b/2)
v_right = v · (1 + κ·b/2)
```

A demand of κ = 5 1/m is a 200 mm radius turn at 0.2 m/s and a 200 mm radius
turn at 0.5 m/s. One set of gains, every speed.

### 3.2 The error signal

Five TCRT5000 channels at 20 mm pitch, at lateral offsets
x = {−40, −20, 0, +20, +40} mm. Each channel is normalised against its **own**
calibration — the five devices differ measurably in LED output and
phototransistor gain, so a single global threshold throws away resolution:

```
n_i = clamp( (raw_i − MIN_i) / (MAX_i − MIN_i), 0, 1 )
```

Channels below `ON_LINE_FRACTION` (0.45) are floor and are discarded. What
remains is squared — this sharpens the centroid against stray reflections — and
used as a weight:

```
w_i = ((n_i − 0.45) / 0.55)²
e   = Σ(w_i · x_i) / Σ(w_i)          [millimetres, then converted to metres]
```

This is the one place where the firmware improves on the Webots prototype. The
simulator had three binary sensors, so its error could only take the five values
{−1, −0.5, 0, +0.5, +1}. Those discrete steps are what forced such heavy
derivative filtering in the simulation. Five analog channels give a continuous
error, so the derivative term is usable.

### 3.3 PID

```
κ = Kp·e + Ki·∫e dt + Kd·ė
```

with `Kp = 34`, `Ki = 0.35`, `Kd = 1.30`, and κ clamped to ±14 1/m (a 71 mm
minimum radius, tighter than any corner we expect).

Three details that matter more than the gain values:

- **The derivative is low-pass filtered** (α = 0.30). The ADC noise floor is a
  couple of LSB; raw differentiation would put that straight into the motors.
- **The integral is clamped** to ±1.5 and **frozen while the line is lost**.
  Integrating blind is how a recovering car drives itself off the track.
- **The integral only accumulates while tracking.** A long corner cannot wind it
  up into an overshoot on the following straight.

### 3.4 The speed schedule — where the time is won

Speed is chosen *from the curvature the controller is about to demand*, before
that curvature is applied. Two independent ceilings, take the lower of the two:

```
v_wheel = V_MAX / (1 + |κ|·b/2)          # the outer wheel saturates here
v_curve = V_STRAIGHT / (1 + 0.075·|κ|)   # grip and tracking-margin comfort limit
v       = max(V_FLOOR, min(V_STRAIGHT, v_wheel, v_curve))
```

`v_wheel` is not a tuning parameter — it is arithmetic. At curvature κ the outer
wheel must run at `v·(1 + κ·b/2)`, so any faster and the wheel is clipped, the
actual curvature is not what was asked for, and the car runs wide. `v_curve` is
the tunable one, and 0.075 came out of the Webots sweep in
`../Folder B/Simulation/SIMULATION.md`.

The sensor bar leads the drive axle by 138 mm, so by the time the error rises,
the car has 138 mm of travel in which to shed speed. At 0.52 m/s and a 2.2 m/s²
slew limit that is enough to reach corner speed before the axle reaches the
corner. **This is the "tweak of our own" the concept notes referred to.**

### 3.5 Saturation handling

If either wheel would exceed its maximum, **both** are scaled by the same
factor:

```
s = ω_max / max(|ω_L|, |ω_R|);   ω_L·= s;   ω_R·= s
```

This preserves the ratio between the wheels, and therefore the path curvature.
The car still takes the corner on the radius it asked for — it just takes it
slower. Clamping only the fast wheel would change the radius and run the car
wide, which is the classic way a fast line follower loses a corner.

---

## 4. The main control loop

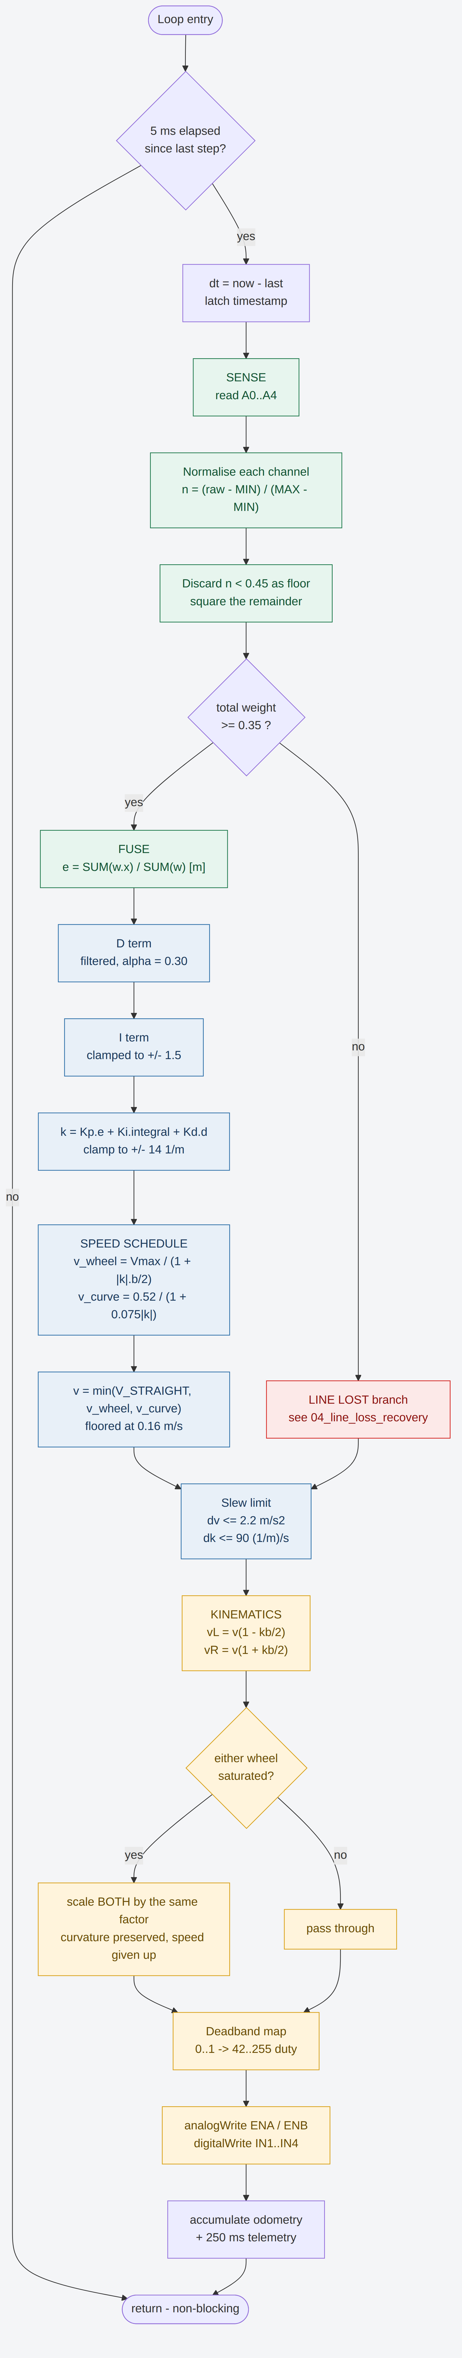
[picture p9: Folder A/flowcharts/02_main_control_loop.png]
Main control loop


**Timing budget at 200 Hz (5 ms):**

| Stage | Cost |
|---|---|
| 5 × `analogRead()` | ~520 µs (104 µs per conversion) |
| Normalise, centroid, PID, schedule | ~180 µs (float maths on an AVR) |
| Kinematics, slew, deadband, PWM writes | ~60 µs |
| **Total** | **~760 µs — 15 % of the period** |

The remaining 85 % is headroom. Telemetry runs at 4 Hz and is the only thing
that ever touches the serial port.

---

## 5. Supervisory state machine

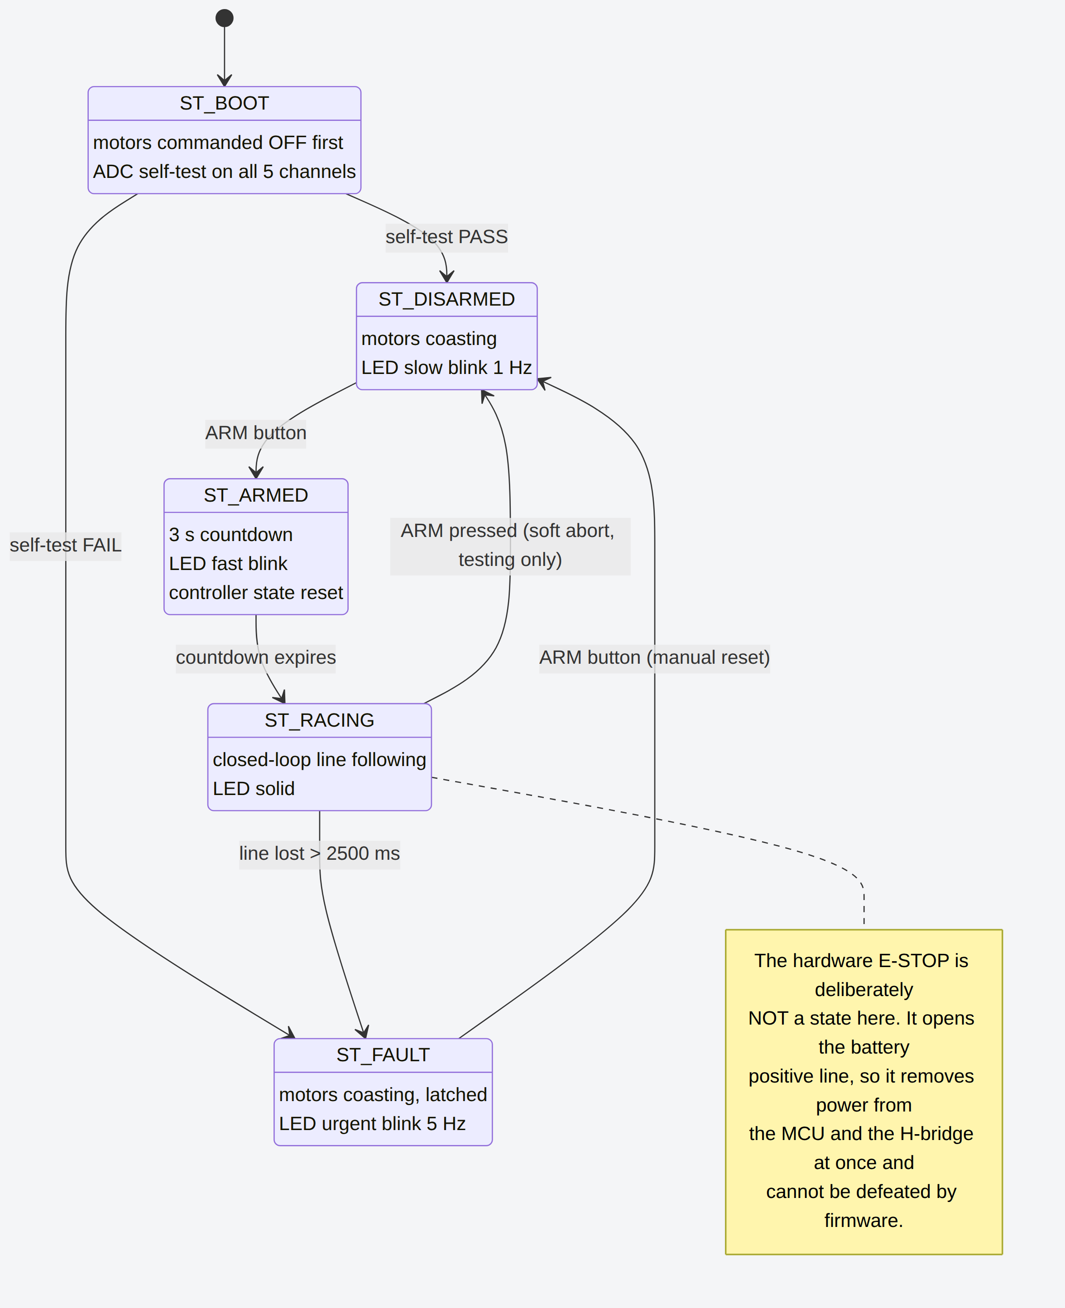
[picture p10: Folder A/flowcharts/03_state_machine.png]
State machine


Five states, and the motors are commanded off in `setup()` before anything else
runs — including before the pin modes are set, so a brown-out reset cannot leave
a wheel driven.

The **E-Stop is deliberately not a state**. It opens the battery positive line,
which removes power from the MCU and the H-bridge in the same instant. Modelling
it in firmware would imply software could observe or override it; it cannot, and
that is the point.

`ST_FAULT` latches. A car that has lost the line and stopped does not restart
itself — a human presses ARM.

---

## 6. Line-loss recovery

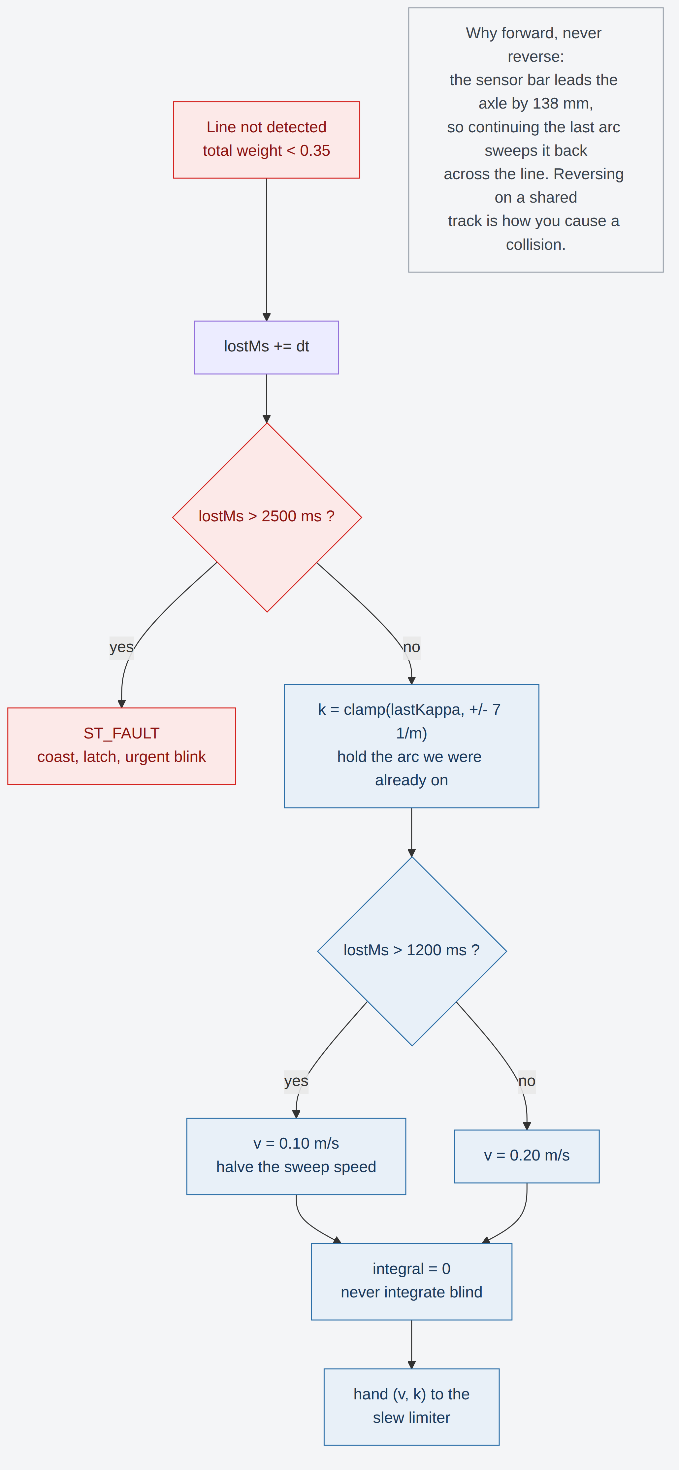
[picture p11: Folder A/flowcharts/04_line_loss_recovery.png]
Line loss recovery


The car **always continues forward** and never reverses. Two reasons:

1. The sensor bar leads the axle by 138 mm. Continuing the arc the car was
   already on sweeps the bar back across the line — geometrically, that is where
   the line is.
2. Reversing on a shared track is how you cause a collision with a car behind
   you.

After 1200 ms the sweep speed halves; after 2500 ms the car enters `ST_FAULT`
and stops. Stopping is the correct failure mode for an autonomous racer: a
stationary car is a hazard a marshal can deal with, a car searching at speed is
not.

---

## 7. Power and safety chain in software terms

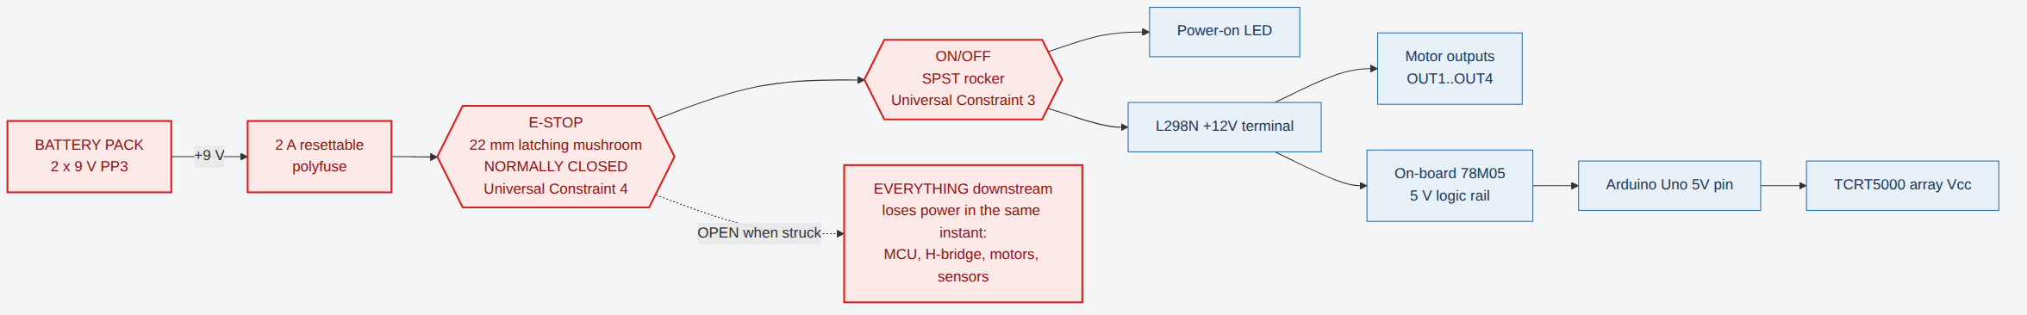
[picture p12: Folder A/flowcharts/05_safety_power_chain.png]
Safety power chain


There is nothing for software to do here, and that is the design. The full
electrical drawing is in `../Folder B/Schematics/01_power_safety_chain.svg`.

---

## 8. Category alignment

Robo Grand Prix is autonomous racing. This firmware:

- has **no radio, Wi-Fi, Bluetooth or serial command path** — `Serial` is
  written to and never read;
- takes exactly one human input, the ARM button, pressed before the run;
- follows a line and manages speed — there is no weapon code, no combat logic,
  no teleoperation, and nothing from another category.

---

## 9. File map

```
Folder A/
├── PROGRAMMING.md                       this document
├── firmware/
│   ├── lightning_mcqueen/
│   │   ├── lightning_mcqueen.ino        200 Hz superloop + state machine
│   │   └── config.h                     every tunable, each one traceable
│   └── calibration/
│       └── calibration.ino              sensor / trim / deadband measurement
├── simulation/
│   └── robograndprix_sim.cpp            Webots controller (control-law origin)
└── flowcharts/
    ├── 01_system_architecture.mmd/.png
    ├── 02_main_control_loop.mmd/.png
    ├── 03_state_machine.mmd/.png
    ├── 04_line_loss_recovery.mmd/.png
    └── 05_safety_power_chain.mmd/.png
```

Flowchart sources are Mermaid. GitHub renders them inline; the PNGs are provided
for the pitch deck and for offline reading.

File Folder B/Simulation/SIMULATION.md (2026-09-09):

# Simulation

**Team CO Coders · Lightning McQueen · Robo Rumble 2026 · Robo Grand Prix**

> *Bonus category: Technical Excellence & Simulation — evidence of rigorous
> testing in a simulation environment before physical fabrication.*

---

## 1. Why we simulated first

We wanted the control law settled before any hardware existed, for one specific
reason: **the interesting part of a line follower is not "does it follow the
line", it is "how fast can it go into a corner and still come out on the line".**
Answering that on hardware means repeatedly running a real car off a real track
at increasing speed, which costs sensors, tyres and afternoons.

In simulation we could sweep the speed policy across dozens of runs in minutes,
find the point where the car starts running wide, and understand *why* — which
is what told us the outer wheel saturating, not grip, was the binding constraint.

---

## 2. Environment

| | |
|---|---|
| Simulator | Webots 2023b |
| Robot model | e-puck (differential drive, 2 wheels + 3 ground sensors) |
| Controller | C++, [`../../Folder A/simulation/robograndprix_sim.cpp`](../../Folder%20A/simulation/robograndprix_sim.cpp) |
| Track | `track_circuit.png` floor texture, tightest corner 76 mm radius |
| Time step | 16 ms (62.5 Hz) — Webots' default e-puck basic time step |

A video of the simulated car running the circuit accompanies this submission.

---

## 3. What the e-puck is and is not

The e-puck is not Lightning McQueen. It is 74 mm across with a 52 mm wheel
separation and a 0.129 m/s top speed; our car is 211 mm across with a 170 mm
track and a 0.58 m/s top speed. We were never trying to simulate our vehicle
dimensionally.

**What transfers is the control law**, because the law is written in units that
do not depend on the vehicle:

- error in metres, not in "sensor counts";
- steering output in curvature (1/m), not in "PWM difference";
- the speed schedule expressed as a function of curvature and wheel separation.

Swap `WHEEL_RADIUS`, `AXLE_LENGTH` and `MAX_WHEEL_OMEGA` and the same equations
describe a different car. That is the whole reason for choosing those units, and
it is why the Arduino firmware in `Folder A/firmware` reads as a near-transcription
of the simulation controller.

---

## 4. What the sweeps told us

### 4.1 The outer wheel saturates before grip runs out

The first thing the simulation showed is that the limit on corner speed was not
sliding — it was the outer wheel hitting its own maximum angular velocity. At
curvature κ, the outer wheel must run at `v · (1 + κ·b/2)`. Ask for more and the
wheel is clipped, the *actual* curvature is lower than the *commanded*
curvature, and the car runs wide on exactly the corner where you needed it not
to.

That produced the `v_wheel` ceiling, which is arithmetic rather than a tuned
number:

```
v_wheel = V_MAX / (1 + |κ|·b/2)
```

On the e-puck: 0.129 m/s flat out, but only **0.096 m/s** through the 76 mm
corner before the outer wheel saturates. The measured best lap matched that
prediction, which is what gave us confidence in the model.

### 4.2 Scale both wheels, never clamp one

The corollary. When saturation happens anyway, scaling **both** wheels by the
same factor preserves the ratio between them and therefore the path curvature —
the car takes the corner it asked for, just slower. Clamping only the fast wheel
changes the radius and runs the car wide. This is four lines of code and it was
worth the whole exercise:

```cpp
const double peak = std::max(std::fabs(wl), std::fabs(wr));
if (peak > MAX_WHEEL_OMEGA) {
  const double s = MAX_WHEEL_OMEGA / peak;
  wl *= s; wr *= s;
}
```

### 4.3 The comfort limit needs its own term

`v_wheel` alone still ran the car to the edge of its tracking envelope, with no
margin for sensor error. Adding a second, softer ceiling gave us a single knob
for how aggressive to be:

```
v_curve = V_STRAIGHT / (1 + CORNER_SLOW · |κ|)
```

Sweeping `CORNER_SLOW` in simulation: below 0.04 the car ran wide on the tight
corner; above 0.12 it was leaving obvious time on the table. **0.06** was the
best clean value on the e-puck. We carry **0.075** into the hardware firmware —
slightly more conservative, because the real car has sensor noise, tyre slip and
a deck that flexes, none of which the simulator models.

### 4.4 Discrete sensing is what limits the derivative term

The e-puck has three *binary* ground sensors, so the simulated error can only
take five values: {−1, −0.5, 0, +0.5, +1}. Every change is a step, and
differentiating a step produces an impulse. That is why the simulation
controller runs `D_ALPHA = 0.30` on the derivative and a relatively low
`K_D = 1.1` — most of the derivative's usefulness is being filtered away just to
keep it stable.

**This finding drove a hardware decision.** It is the reason Lightning McQueen
carries **five analog** channels rather than three digital ones. A weighted
centroid over five analog readings is continuous, so the derivative term is
genuinely usable — which is why the hardware firmware runs `K_D = 1.30` with the
same filter constant and gets real damping out of it.

### 4.5 Rate limits are about tracking, not about faking weak motors

Webots motors reach commanded velocity in one time step. Without rate limiting,
the commanded curvature jumped discontinuously with each sensor state change and
the car visibly twitched. `MAX_KAPPA_RATE` and `MAX_LIN_ACCEL` exist to keep the
*commanded path* smooth. The comment in the source says exactly this, because
it is the kind of constant a reader will otherwise assume is a fudge.

---

## 5. Constants that came out of simulation

| Simulation constant | Value | Hardware equivalent | Value | Note |
|---|---|---|---|---|
| `CORNER_SLOW` | 0.060 | `CORNER_SLOW` | 0.075 | More conservative on hardware |
| `D_ALPHA` | 0.30 | `D_ALPHA` | 0.30 | Unchanged |
| `KAPPA_MAX` | 18 1/m | `KAPPA_MAX` | 14 1/m | Scaled to our 170 mm track |
| `K_D` | 1.1 | `K_D` | 1.30 | Raised — analog sensing allows it |
| `RECOVER_KAPPA` | 9 1/m | `RECOVER_KAPPA` | 7 1/m | Scaled to our track |
| forward-only recovery | yes | yes | — | Confirmed in simulation |
| both-wheel scaling | yes | yes | — | The key finding |

`K_P` and `K_I` are **not** carried across, and deliberately so. The simulation's
error is unitless in the range ±1; the firmware's error is a cross-track
distance in metres. `K_P = 26` on a unitless error and `K_P = 34` on an error in
metres are not comparable quantities, and pretending otherwise would be the
easiest way to arrive at a badly tuned car. The hardware gains start from the
geometry (a 20 mm offset should ask for roughly a 1.5 m radius) and get trimmed
on the track.

---

## 6. What simulation did not tell us

Stated plainly, because a simulation section that claims everything transferred
is not worth reading:

- **No tyre model.** Webots' contact model is not a friction circle. Real slip
  angles will show up on the track and nowhere else.
- **No sensor noise, no ambient light.** Real TCRT5000s see track lighting,
  reflections and a floor that is not uniformly white. This is precisely what
  `calibration.ino` exists to measure.
- **No H-bridge deadband.** The simulated motors respond linearly from zero. The
  L298N does not turn a wheel below about 16 % duty, which is why
  `PWM_DEADBAND` exists in the firmware and has no counterpart in the simulator.
- **No battery sag.** The simulated supply is stiff. A PP3 pack under a stall is
  not.
- **Different vehicle.** Every scaled constant in the table above is a
  prediction to be verified on the real car, not a measured result.

The next step is exactly that verification: run `calibration.ino`, then a
speed-schedule sweep on the physical track, and compare against these
predictions.

---

## 7. Files

```
Simulation/
├── SIMULATION.md                          this document
└── grandPrixSimulation_original_notes.md  our original simulation notes

Folder A/simulation/
└── robograndprix_sim.cpp                  the Webots controller
```

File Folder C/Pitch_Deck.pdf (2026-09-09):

R OB O R U M B LE 2 0 2 6 · R OB O GR A N D P R IX

# Lightning McQueen

### An autonomous line-following racer that picks its speed

from the corner it is about to enter — not the one it is already in.

Team CO Coders
Elimination Round submission

### 0.86 kg

against a 5 kg limit

300 × 211 mm
against 500 × 500 mm

R 1 843.60
total cost of implementation

0 1 · I N T R OD U C T ION
The category sets the problem. The constraints set the design.

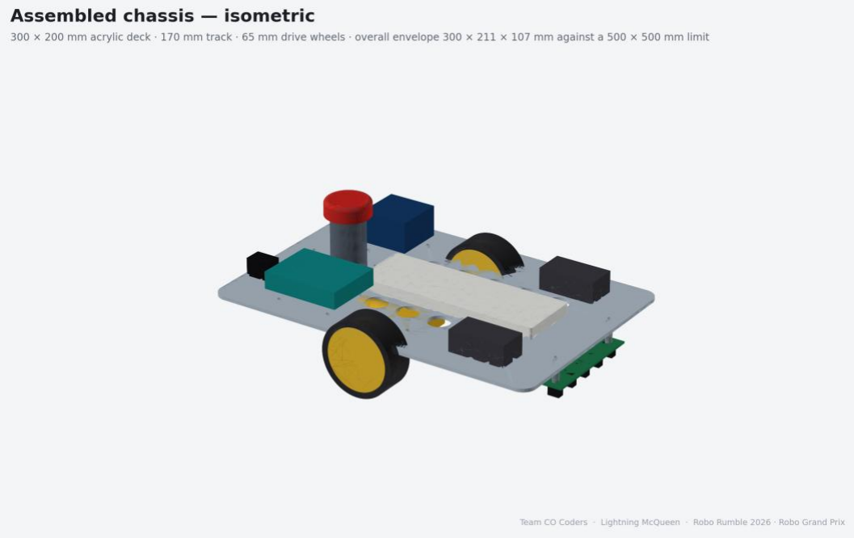
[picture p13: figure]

Team CO Coders · Lightning McQueen · Introduction | 2 / 7

Robo Grand Prix is autonomous racing, so there is no problem to validate — the problem is given: get a robot around a line-marked circuit, on its own, faster than everyone else.

What there is to address is a set of hard constraints. A build either satisfies them or it does not.

Footprint ≤ 50 × 50 cm. We are at 300 × 211 × 107 mm, and the CAD build script asserts it on every run.

Mass below 5 kg. We are at 0.86 kg — 17 % of the allowance.

Accessible ON/OFF switch, and an Emergency Stop. Both drawn, annotated and placed where an operator can actually reach them.

Fully autonomous. No radio, no Wi-Fi, no Bluetooth anywhere on the vehicle. Any human intervention forfeits the run.

0 2 · S OL U T ION

# What we are building

Team CO Coders · Lightning McQueen · Solution | 3 / 7

BUILDABLE, TODAY

Every part is stocked by South African hobby suppliers. The deck is one DXF and ninety seconds on a laser cutter. Nothing here waits on an import order.

Sensing. Five-channel TCRT5000 reflective array, 20 mm pitch, 12 mm above the floor, mounted 138 mm ahead of the drive axle.

Fusion. A weighted centroid over five per-channel-normalised analog readings gives a cross-track error in metres — not a unitless index.

Control. A PID whose output is a path curvature in 1/m, running at 200 Hz on an Arduino Uno.

Drive. Two TT gear motors through an L298N H-bridge, from two 9 V PP3 cells on a single switched rail.

Structure. One 3 mm laser-cut acrylic deck, 300 × 200 mm. Every joint bolted; nothing glued.

0 3 · T H E E D GE
Steer in curvature. Choose speed from the corner you are about to enter.
Team CO Coders · Lightning McQueen · The edge | 4 / 7

200 Hz

control loop, 15 % CPU

5

The naive line follower adds its error to one motor's PWM and subtracts it from the other. The gain that feels right at low speed oversteers at high speed — so you end up tuning one set of gains per speed.

Our PID instead outputs a path curvature κ. A demand of κ = 5 1/m is a 200 mm radius turn at any speed. One set of gains, every speed.

Speed comes from curvature, before the curvature is applied. Two ceilings — the point where the outer wheel saturates, and a grip margin — and we take the lower.

The sensor bar leads the axle by 138 mm. That is the distance in which the car sheds speed, so it arrives at the corner already slowed.

On saturation, both wheels scale together. The path curvature survives; only the speed is given up. Clamping one wheel changes the radius and runs you wide.

0 4 · S A FETY — U N IVE R S A L D ESIGN C ON ST R A IN TS 3 A N D 4

# The E-Stop is the first device in the battery line

Team CO Coders · Lightning McQueen · Safety | 5 / 7

WHY THERE IS NO SEPARATE LOGIC BATTERY

A second supply would keep the MCU alive after the motor rail opened exactly what Constraint 4 exists to prevent. One rail, one stop.

SW1 — E-Stop. 22 mm latching mushroom head, normally closed, on a 48 mm mast at the rear centreline. Tallest object on the car, nothing overhanging it.

SW2 — ON/OFF. SPST rocker at the rear-left corner, operable with the car on the grid — no lifting, no reaching over a wheel.

Everything is downstream. The L298N's 78M05 derives the 5 V logic rail from the same switched line, so one strike de-energises the motors, the H-bridge, the MCU and the sensors together.

Firmware cannot defeat it. The contact is mechanically in series with the battery. Nothing is left running once it opens.

Stored energy cannot move the car. 100 µF at 5 V is 1.25 mJ; turning a loaded TT gearbox needs about a joule.

0 5 · C OST OF I M PLE M E N TAT ION

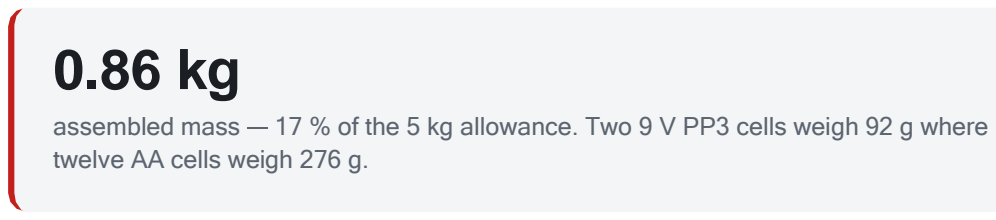
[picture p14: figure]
twelve AA cells weigh 276 g.
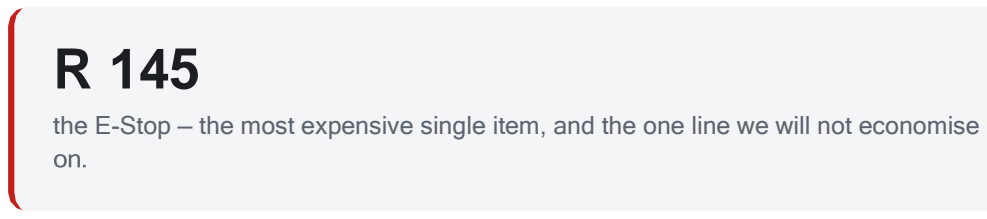
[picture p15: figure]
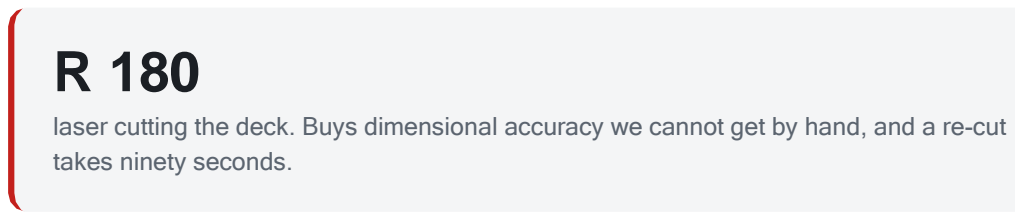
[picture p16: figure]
takes ninety seconds.

Team CO Coders · Lightning McQueen · Cost | 6 / 7

# R 1 843.60, all in

CATEGORY | COST | SHARE
Control & drive electronics | R 480.00 | 28.6 %
Chassis & hardware | R 440.00 | 26.3 %
Power & safety | R 301.00 | 18.0 %
Interconnect | R 230.00 | 13.7 %
Sensing | R 167.00 | 10.0 %
Indication & passives | R 58.00 | 3.5 %
Contingency — spares and breakage (10 %) | R 167.60 | —
TOTAL COST OF IMPLEMENTATION | R 1 843.60

24 line items, 28 units. Full breakdown with quantities, suppliers, stock codes and buy links in Bill_of_Materials.xlsx.

assembled mass 17 % of the 5 kg allowance. Two 9 V PP3 cells weigh 92 g where

the E-Stop — the most expensive single item, and the one line we will not economise

laser cutting the deck. Buys dimensional accuracy we cannot get by hand, and a re-cut

0 6 · TE A M

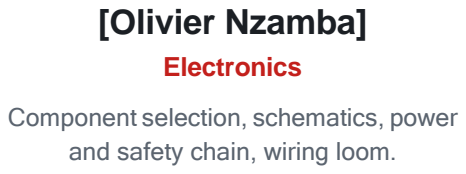
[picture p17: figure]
[Olivier Nzamba]; Electronics; Component selection, schematics, power and safety chain, wiring loom.
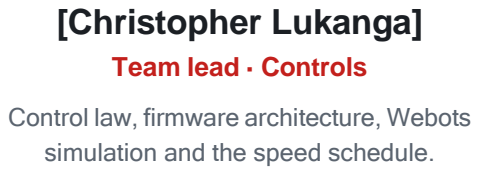
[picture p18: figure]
[Christopher Lukanga]; Team lead · Controls; simulation and the speed schedule.

Team CO Coders · Lightning McQueen · Team | 7 / 7

Control law, firmware architecture, Webots

# Team CO Coders

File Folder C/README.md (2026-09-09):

# Folder C — Documentation

| File | What it is |
|---|---|
| [`Pitch_Deck.pdf`](Pitch_Deck.pdf) | 7 slides — introduction, solution, technical approach, cost, team |
| [`Bill_of_Materials.xlsx`](Bill_of_Materials.xlsx) | Every component: quantity, unit cost, supplier, stock code, buy link. **Total highlighted in red.** |
| [`Holistic_Build_Document.md`](Holistic_Build_Document.md) | The full written report — constraints, solution, BOM summary, and the mechanical / electronic / programming sub-sections |
| [`FQA_Attendance_Log.md`](FQA_Attendance_Log.md) | Facilitator Q&A attendance logbook |
| [`FQA_Proof/`](FQA_Proof) | Attendance screenshots referenced by the logbook |

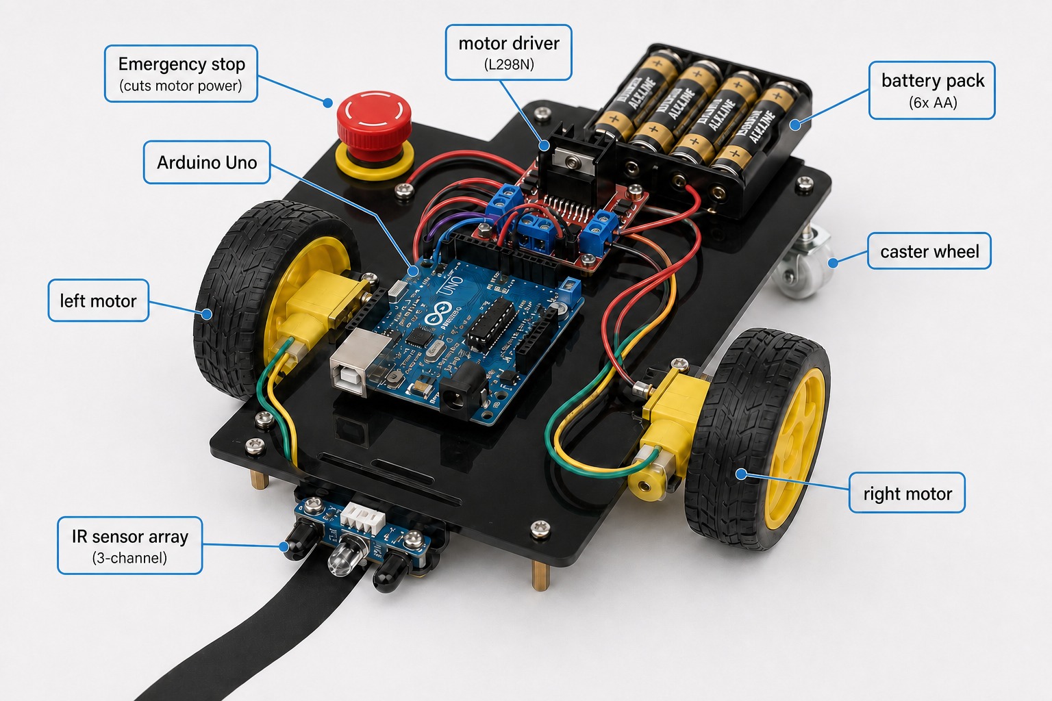
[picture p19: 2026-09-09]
Folder B/Mechanical Design/renders/WhatsApp Image 2026-09-09 at 3.36.30 PM.jpeg

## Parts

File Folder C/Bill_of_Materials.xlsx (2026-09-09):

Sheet: Bill of Materials
LIGHTNING McQUEEN — BILL OF MATERIALS
Team CO Coders · Robo Rumble 2026 · Robo Grand Prix · Elimination Round submission
All prices in South African Rand (ZAR)
# | Component | Qty | Cost per unit (ZAR) | Line total (ZAR) | Supplier | Supplier stock code | Direct link to buy | Function / justification
CONTROL & DRIVE ELECTRONICS
1 | Arduino Uno R3 (ATmega328P, 16 MHz) | 1 | 250 | 250 | Micro Robotics | VERIFY | https://www.robotics.org.za/ | Control unit. 5 ADC channels + Timer1 PWM.
2 | L298N dual H-bridge motor driver module | 1 | 85 | 85 | Micro Robotics | VERIFY | https://www.robotics.org.za/ | 2 A/channel. On-board 78M05 supplies the 5 V logic rail.
3 | TT gear motor 1:48 with 65 mm wheel | 2 | 55 | 110 | Micro Robotics | VERIFY | https://www.robotics.org.za/ | Drive. ~170 rpm loaded on 9 V.
4 | Ball castor, 20 mm | 1 | 35 | 35 | Micro Robotics | VERIFY | https://www.robotics.org.za/ | Tail support.
SENSING
5 | TCRT5000 5-channel reflective array module | 1 | 135 | 135 | Micro Robotics | TRCT5000-4C | https://www.robotics.org.za/TRCT5000-4C | Line sensing. 20 mm pitch, mounted at 12 mm ride height.
6 | TCRT5000 single adjustable module (spare) | 1 | 32 | 32 | Micro Robotics | TCRT5000-ADJ | https://www.robotics.org.za/TCRT5000-ADJ | Spare / bench-test channel.
POWER & SAFETY
7 | 9 V PP3 alkaline battery | 2 | 45 | 90 | Communica | VERIFY | https://www.communica.co.za/ | 2 cells in series-parallel: 9 V, ~1.2 Ah.
8 | 9 V PP3 battery holder with flying leads | 2 | 18 | 36 | Communica | VERIFY | https://www.communica.co.za/ | Hook-and-loop mounted for fast swaps between heats.
9 | 22 mm latching mushroom E-Stop, NC contact | 1 | 145 | 145 | Communica | VERIFY | https://www.communica.co.za/ | MANDATORY - Universal Design Constraint 4. First device in the battery positive line.
10 | SPST rocker switch, panel mount | 1 | 18 | 18 | Communica | VERIFY | https://www.communica.co.za/ | MANDATORY - Universal Design Constraint 3. Rear-left corner of the deck.
11 | Resettable polyfuse, 2 A hold | 1 | 12 | 12 | Communica | VERIFY | https://www.communica.co.za/ | Overcurrent protection ahead of the E-Stop.
INDICATION & PASSIVES
12 | Momentary pushbutton (ARM) | 1 | 8 | 8 | Communica | VERIFY | https://www.communica.co.za/ | Pre-run arm button, INPUT_PULLUP.
13 | 5 mm LED (power + status) | 2 | 3 | 6 | Communica | VERIFY | https://www.communica.co.za/ | D1 power-on, D2 state blink codes.
14 | Resistor assortment (220 R, 1 k) | 1 | 25 | 25 | Communica | VERIFY | https://www.communica.co.za/ | LED current limiting.
15 | Piezo buzzer, 5 V | 1 | 15 | 15 | Communica | VERIFY | https://www.communica.co.za/ | Audible arm, countdown and fault.
16 | Electrolytic capacitor, 100 uF 16 V | 1 | 4 | 4 | Communica | VERIFY | https://www.communica.co.za/ | 5 V rail bulk decoupling.
INTERCONNECT
17 | 830-point solderless breadboard | 1 | 75 | 75 | Micro Robotics | VERIFY | https://www.robotics.org.za/ | Main interconnect, deck centreline.
18 | Jumper wire set (M-M / M-F, 120 pcs) | 1 | 95 | 95 | Micro Robotics | VERIFY | https://www.robotics.org.za/ | Wiring loom.
19 | Heat-shrink assortment and solder | 1 | 60 | 60 | Communica | VERIFY | https://www.communica.co.za/ | Loom termination.
CHASSIS & HARDWARE
20 | Cast acrylic sheet 3 mm, 300 x 200 mm, laser cut to DXF | 1 | 180 | 180 | Local laser-cutting service | VERIFY | local supply — see note | Deck plate. Cut from Folder B/Mechanical Design/CAD/deck_plate_laser_cut.dxf
21 | M3 nylon standoff kit (8 mm and 30 mm) | 1 | 120 | 120 | Communica | VERIFY | https://www.communica.co.za/ | Nylon, not steel - steel standoffs beside the IR emitters reflect.
22 | M3 bolts and nyloc nuts assortment | 1 | 85 | 85 | Communica | VERIFY | https://www.communica.co.za/ | Every joint bolted, none glued.
23 | Hook-and-loop strap, 25 mm | 1 | 25 | 25 | Local hardware | VERIFY | local supply — see note | Battery pack retention - 10 second swap.
24 | PLA filament for the E-Stop mast (est. 40 g) | 1 | 30 | 30 | Micro Robotics | VERIFY | https://www.robotics.org.za/ | 3D printed, 30 mm dia x 48 mm, 4 perimeters, 40% infill.
 | Subtotal — components |  |  | 1676
 | Contingency — spares and breakage (10%) |  | 10.0% | 167.6 |  |  |  | One spare sensor array and one spare TT motor cover the two parts most likely to be damaged in testing.
 | TOTAL COST OF IMPLEMENTATION |  |  | 1843.6 | ◄ TOTAL, IN RED AS REQUIRED
 | Unit count |  |  | 28
 | Line items |  |  | 24

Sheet: Cost by category
COST BY CATEGORY
Derived from the Bill of Materials sheet — no numbers are typed here.
Category | Cost (ZAR) | Share of total | Note
Control & drive electronics | 480 | 28.6% | The Uno and L298N are the two parts a judge will ask about; both were chosen for availability over outright performance.
Sensing | 167 | 10.0% | Five analog channels rather than three digital ones — the single most consequential electronic decision on the car.
Power & safety | 301 | 18.0% | Includes both mandatory safety devices. The E-Stop is the most expensive single item and is not negotiable.
Indication & passives | 58 | 3.5% | Cheap, and what lets a marshal read the car's state from the side of the track.
Interconnect | 230 | 13.7% | The 830-point breadboard our concept committed to, plus the loom.
Chassis & hardware | 440 | 26.3% | Laser cutting is the largest line here and buys dimensional accuracy we cannot get by hand.
Subtotal — components | 1676 | 100.0%
Contingency (10%) | 167.6
TOTAL COST OF IMPLEMENTATION | 1843.6
COMPETITION COMPLIANCE
Footprint | 300 × 211 × 107 mm against a 500 × 500 mm limit
Mass | 0.86 kg against a 5 kg limit (17% of the allowance)
ON/OFF switch | SW2, SPST rocker — line 10 of the BOM
Emergency Stop | SW1, 22 mm latching NC — line 9 of the BOM

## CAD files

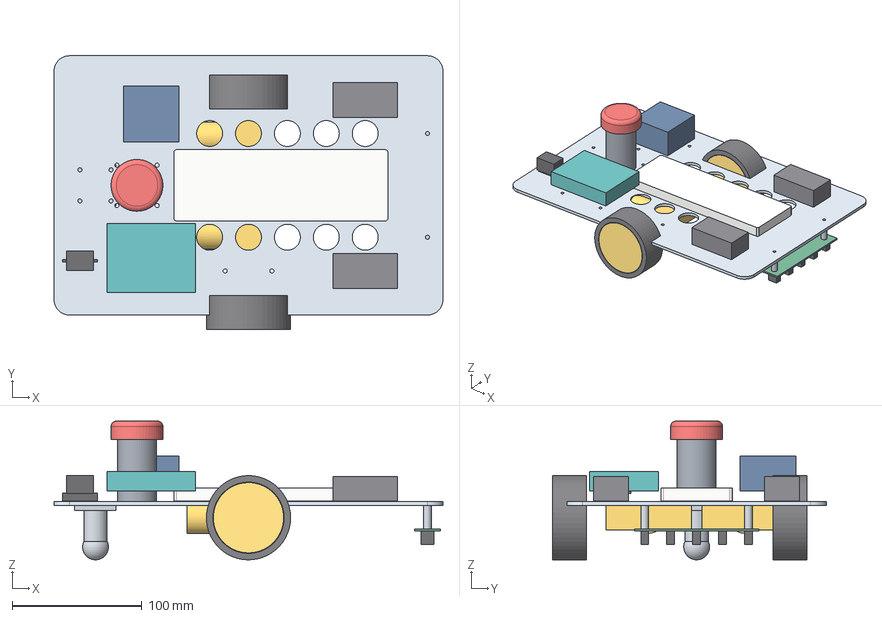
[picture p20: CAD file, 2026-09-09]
Folder B/Mechanical Design/CAD/lightning_mcqueen_assembly.step
300.0 x 211.0 x 107.0 mm
base_plate
tyre_left
tyre_right
rim_left
rim_right
motor_left
motor_right
castor
sensor_pcb
sensor_packages
sensor_standoffs
breadboard
arduino_uno
l298n
batteries
estop_mast
estop_head
power_switch

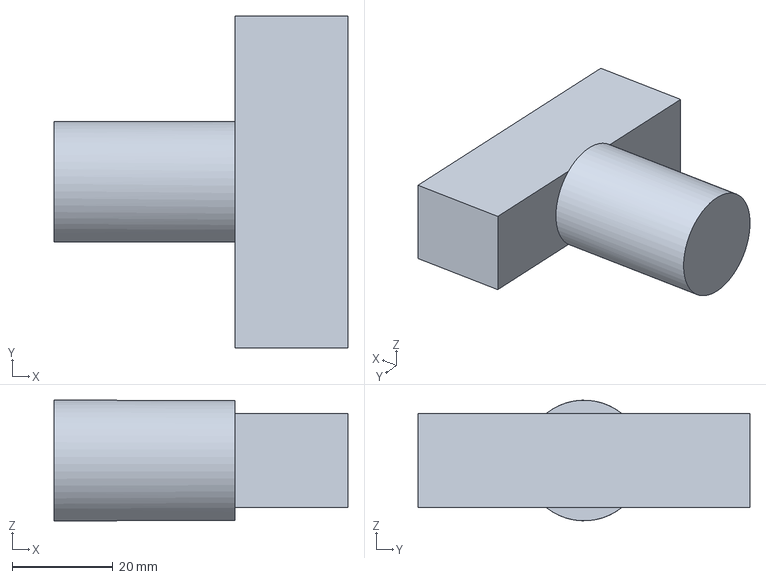
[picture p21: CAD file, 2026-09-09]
Folder B/Mechanical Design/CAD/STEP/motor_right.step
58.5 x 66.0 x 24.0 mm

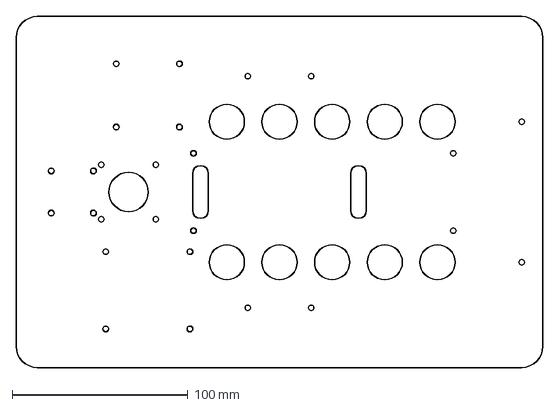
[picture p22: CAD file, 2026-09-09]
Folder B/Mechanical Design/CAD/deck_plate_laser_cut.dxf
300.0 x 200.0 mm

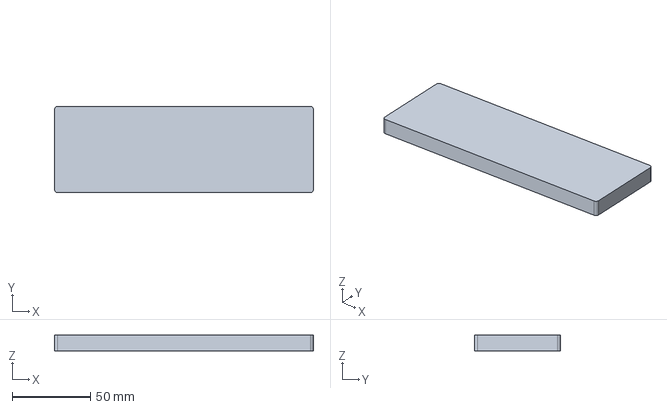
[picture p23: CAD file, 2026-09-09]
Folder B/Mechanical Design/CAD/STEP/breadboard.step
165.0 x 55.0 x 10.0 mm

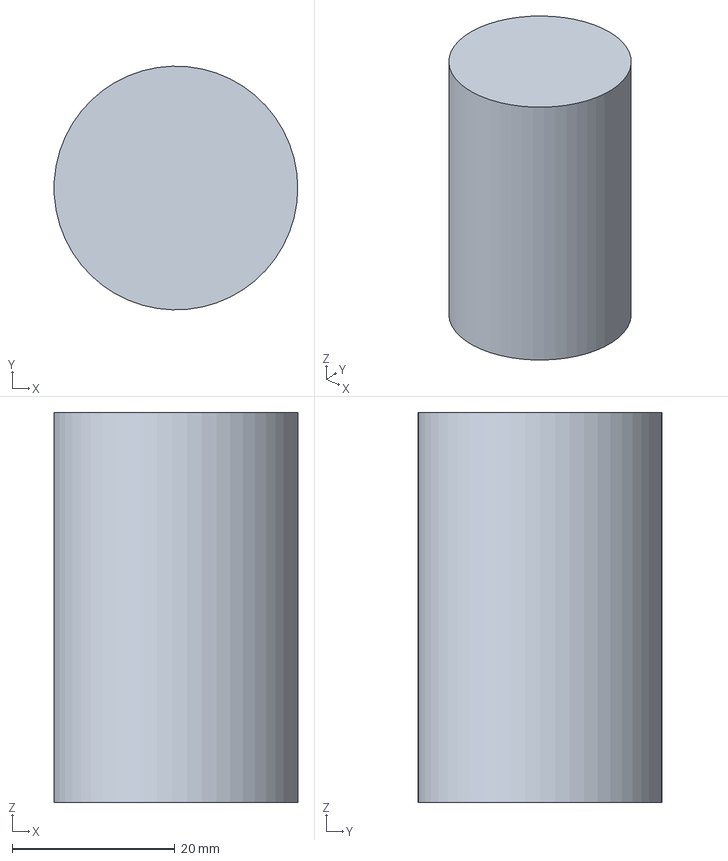
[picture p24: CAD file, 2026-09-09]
Folder B/Mechanical Design/CAD/STEP/estop_mast.step
30.0 x 30.0 x 48.0 mm

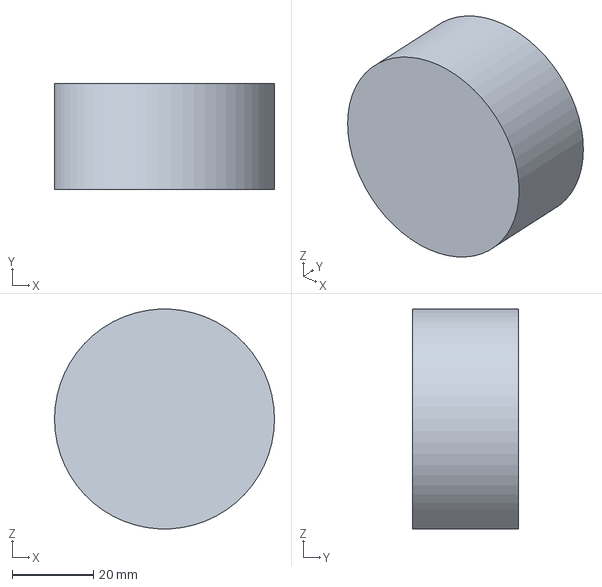
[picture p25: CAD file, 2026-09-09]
Folder B/Mechanical Design/CAD/STEP/rim_right.step
54.2 x 26.0 x 54.1 mm

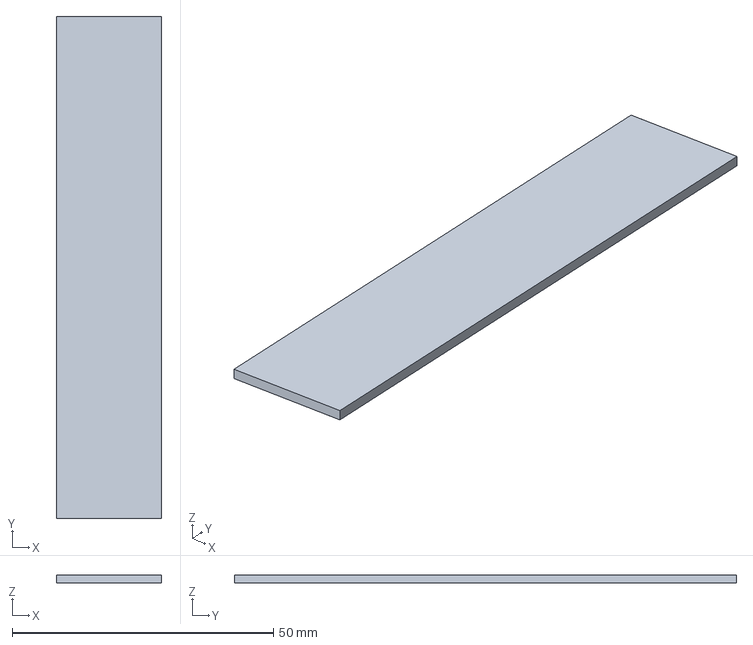
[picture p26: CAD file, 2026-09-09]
Folder B/Mechanical Design/CAD/STEP/sensor_pcb.step
20.0 x 96.0 x 1.60 mm

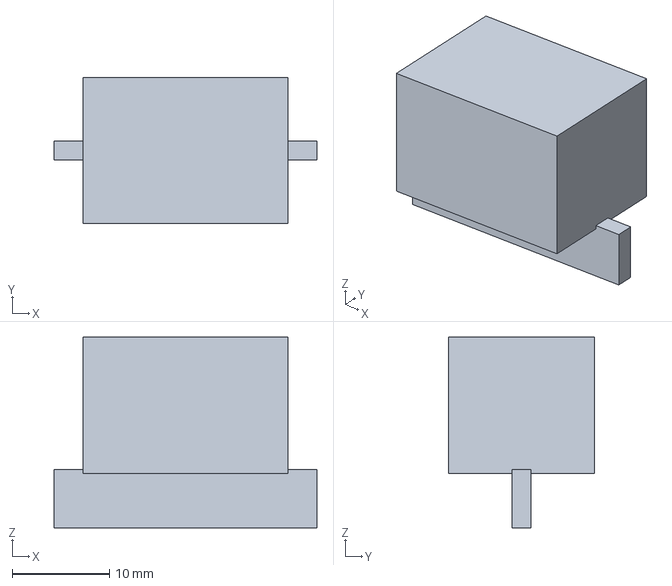
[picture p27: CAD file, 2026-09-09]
Folder B/Mechanical Design/CAD/STEP/power_switch.step
27.0 x 15.0 x 19.6 mm

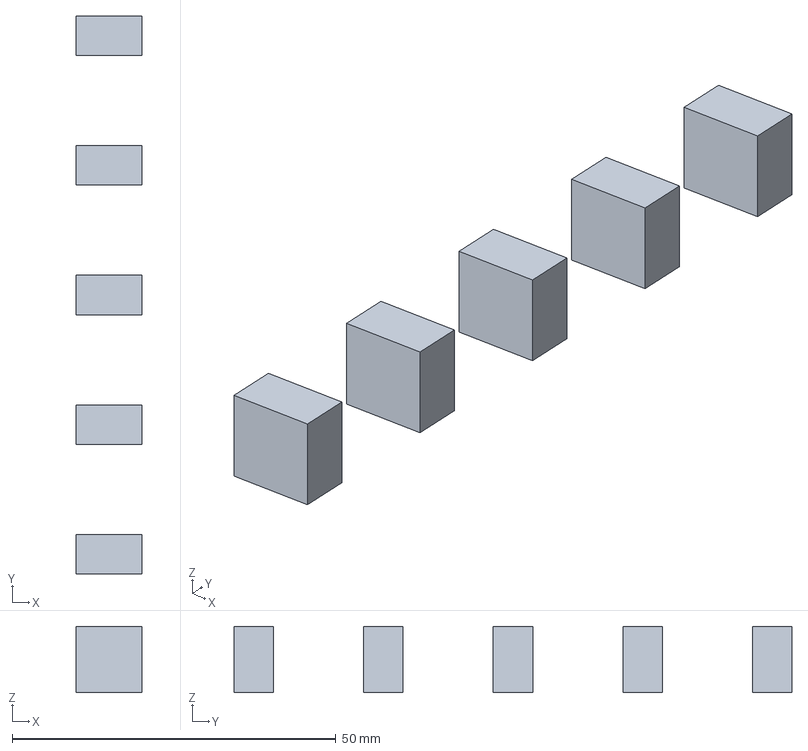
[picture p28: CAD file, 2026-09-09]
Folder B/Mechanical Design/CAD/STEP/sensor_packages.step
10.2 x 86.1 x 10.2 mm

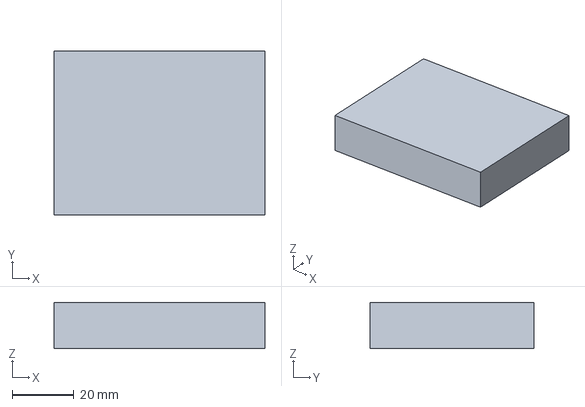
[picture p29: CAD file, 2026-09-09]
Folder B/Mechanical Design/CAD/STEP/arduino_uno.step
68.6 x 53.4 x 15.0 mm

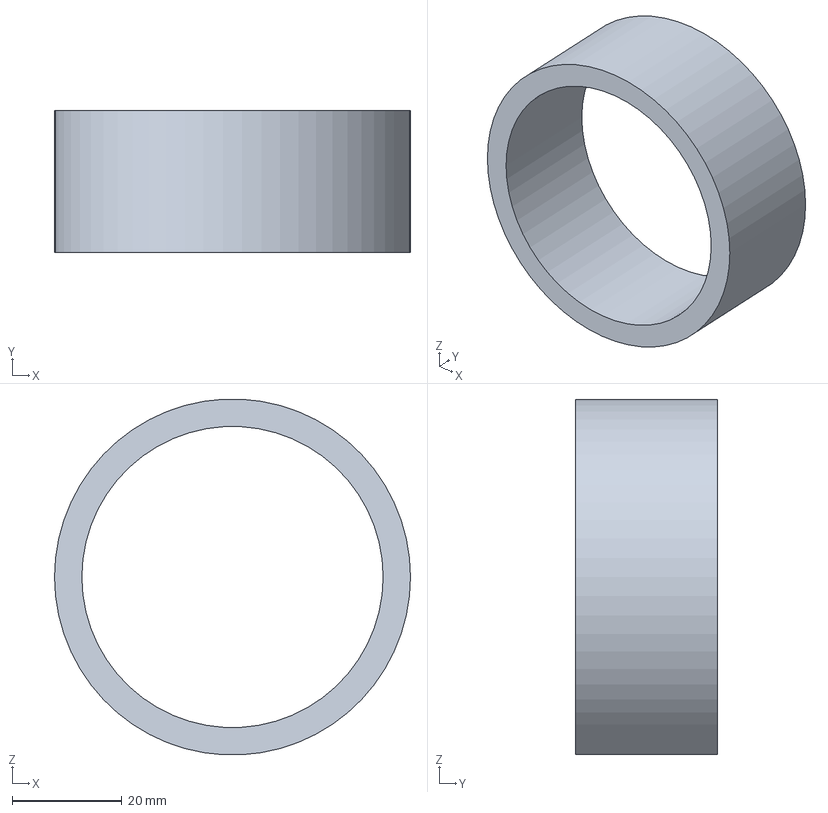
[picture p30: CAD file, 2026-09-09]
Folder B/Mechanical Design/CAD/STEP/tyre_left.step
65.0 x 26.0 x 64.9 mm

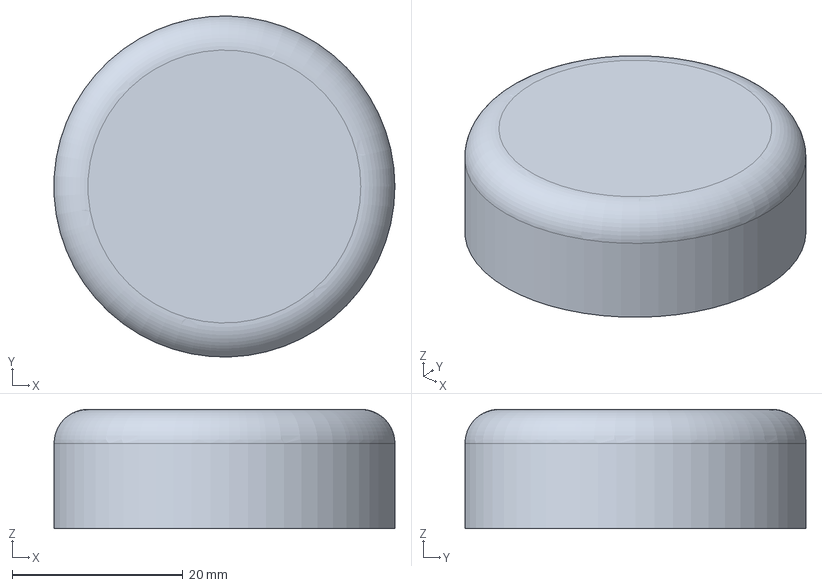
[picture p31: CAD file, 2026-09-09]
Folder B/Mechanical Design/CAD/STEP/estop_head.step
40.0 x 40.0 x 14.0 mm

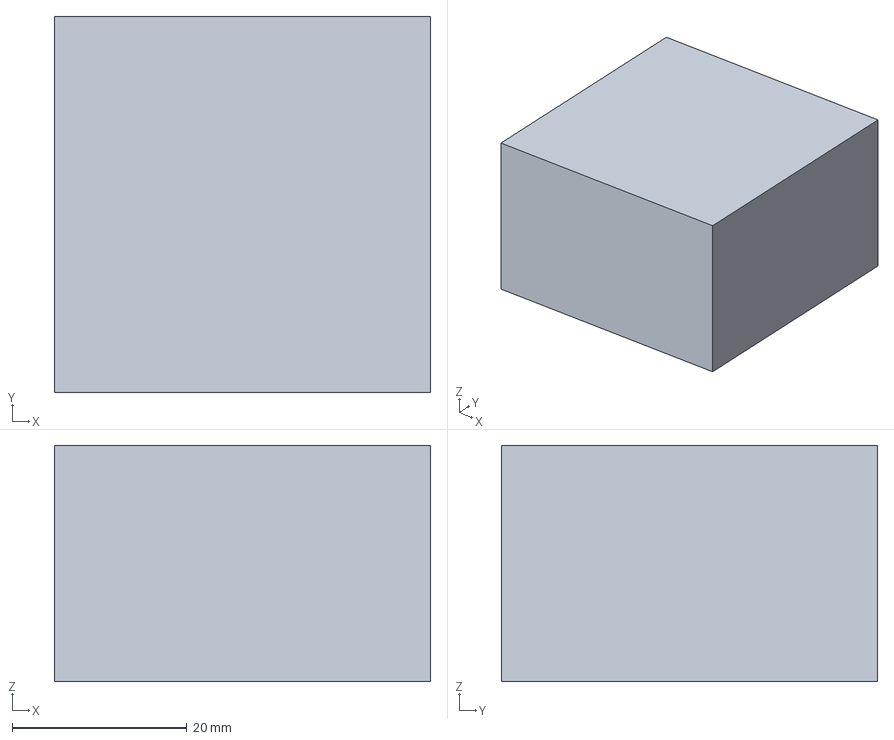
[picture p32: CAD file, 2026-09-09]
Folder B/Mechanical Design/CAD/STEP/l298n.step
43.0 x 43.0 x 27.0 mm

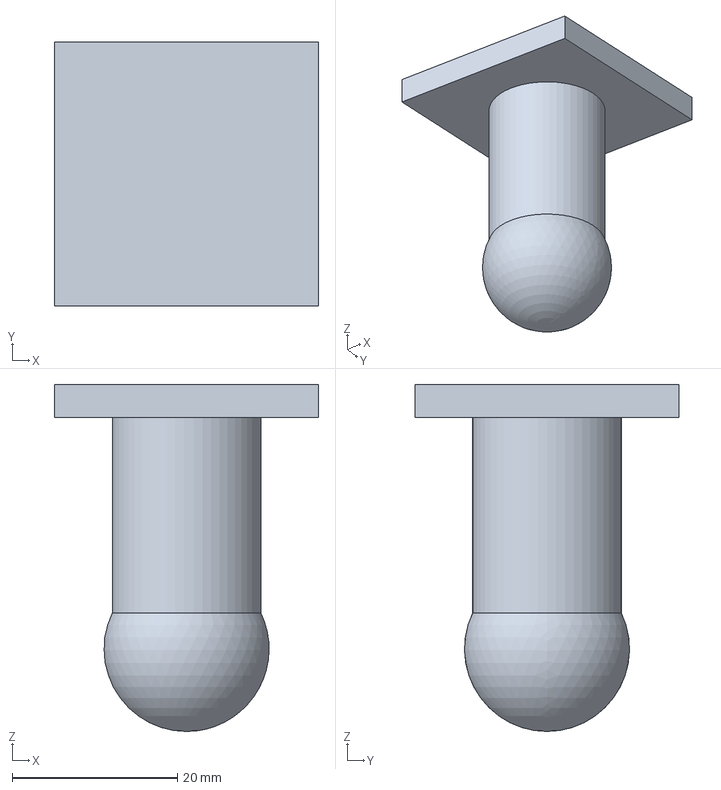
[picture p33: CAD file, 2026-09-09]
Folder B/Mechanical Design/CAD/STEP/castor.step
32.0 x 32.0 x 42.0 mm

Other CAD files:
Folder B/Mechanical Design/CAD/STEP/motor_left.step
Folder B/Mechanical Design/CAD/STEP/rim_left.step
Folder B/Mechanical Design/CAD/STEP/sensor_standoffs.step
Folder B/Mechanical Design/CAD/STEP/base_plate.step
Folder B/Mechanical Design/CAD/STEP/batteries.step
Folder B/Mechanical Design/CAD/STEP/tyre_right.step
Folder B/Mechanical Design/CAD/STL/arduino_uno.stl
Folder B/Mechanical Design/CAD/STL/base_plate.stl
Folder B/Mechanical Design/CAD/STL/batteries.stl
Folder B/Mechanical Design/CAD/STL/breadboard.stl
Folder B/Mechanical Design/CAD/STL/castor.stl
Folder B/Mechanical Design/CAD/STL/estop_head.stl
Folder B/Mechanical Design/CAD/STL/estop_mast.stl
Folder B/Mechanical Design/CAD/STL/l298n.stl
Folder B/Mechanical Design/CAD/STL/motor_left.stl
Folder B/Mechanical Design/CAD/STL/motor_right.stl
Folder B/Mechanical Design/CAD/STL/power_switch.stl
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

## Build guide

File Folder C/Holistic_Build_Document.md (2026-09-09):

# Lightning McQueen — Holistic Build Document

**Team Name:** CO Coders
**Solution Name:** Lightning McQueen
**Category:** Robo Grand Prix (autonomous racing)
**Event:** Robo Rumble 2026 — Elimination Round

---

## 1. Context and competition constraints

Robo Grand Prix is autonomous racing. There is no problem statement to validate,
because the problem is given: get a robot around a line-marked circuit, on its
own, faster than everyone else. What there *is* to address is a set of hard
constraints, and a build either satisfies them or it does not.

| Constraint | Requirement | How Lightning McQueen addresses it |
|---|---|---|
| **Footprint** | ≤ 500 × 500 mm | **300 × 211 × 107 mm.** The CAD build script asserts this on every run and fails loudly if a parameter change ever breaks it. |
| **Mass** | strictly below 5 kg | **0.86 kg** — 17 % of the allowance. Full budget in §6.1. |
| **ON/OFF switch** | mandatory, easily accessible | **SW2**, SPST rocker at the rear-left corner of the deck. Operable with the car on the grid. |
| **Emergency Stop** | mandatory, cuts power instantly, clearly annotated | **SW1**, 22 mm latching mushroom head on a 48 mm mast at the rear centreline, wired **first** in the battery positive line. |
| **Full autonomy** | no remote control, no Wi-Fi, no human contact during the run | No radio, no Wi-Fi, no Bluetooth, no serial command path anywhere on the vehicle. |

### The constraints as an advantage

The mass and size limits are generous for a line follower, and we treated the
headroom as something to spend deliberately rather than something to ignore.
Every gram not on the car is a gram the same TT gearboxes do not have to
accelerate and the same tyres do not have to hold through a corner. That is why
the deck is 3 mm acrylic rather than 5 mm, why the fasteners are nylon rather
than steel, and — the decision our concept notes committed to first — why the
car runs on **two 9 V PP3 cells rather than twelve 1.5 V AA cells**: 92 g against
276 g, on a car whose entire assembled mass is 855 g.

The honest cost of that choice is capacity. Two PP3 cells give roughly 1.2 Ah at
9 V, which is comfortable for a heat but not for an afternoon of testing, and the
terminal voltage sags under a stall. We mitigate by swapping packs between heats
(hook-and-loop straps, ten seconds) and by bench-testing from a supply rather
than from cells.

---

## 2. Solution overview

We are building an autonomous line-following racer that:

- reads the track with a **five-channel TCRT5000 reflective array** at 20 mm
  pitch, 12 mm above the floor, mounted 138 mm ahead of the drive axle;
- computes a **cross-track error in metres** from a weighted centroid of those
  five analog channels;
- runs a **PID whose output is a path curvature** (1/m), not a motor difference;
- chooses its **speed from that curvature**, before the curvature is applied, so
  the car is already at corner speed when the corner arrives;
- drives two TT gear motors through an L298N H-bridge from an Arduino Uno at
  200 Hz;
- and stops safely and stays stopped when it loses the line.

**The strategy in one line.** Most line followers lose time because they brake
for corners they have already entered. Ours sheds speed during the 138 mm of
travel between the sensor bar detecting the corner and the axle reaching it.

---

## 3. BOM summary

Core components only. The complete breakdown — quantities, unit costs,
suppliers, stock codes and buy links — is in
[**`Bill_of_Materials.xlsx`**](./Bill_of_Materials.xlsx), where the total is
highlighted in red.

| Component | Qty | Function |
|---|---:|---|
| [Arduino Uno R3](./Bill_of_Materials.xlsx) | 1 | Control — 5 ADC channels, Timer1 PWM |
| [L298N dual H-bridge module](./Bill_of_Materials.xlsx) | 1 | Motor drive + 5 V logic regulation |
| [TCRT5000 5-channel array](https://www.robotics.org.za/TRCT5000-4C) | 1 | Line sensing |
| [TT gear motor 1:48 + 65 mm wheel](./Bill_of_Materials.xlsx) | 2 | Drive |
| [9 V PP3 cell + holder](./Bill_of_Materials.xlsx) | 2 | Power |
| [22 mm latching E-Stop, NC](./Bill_of_Materials.xlsx) | 1 | **Constraint 4** |
| [SPST rocker switch](./Bill_of_Materials.xlsx) | 1 | **Constraint 3** |
| [830-point breadboard](./Bill_of_Materials.xlsx) | 1 | Interconnect |
| [3 mm acrylic deck, laser cut](./Bill_of_Materials.xlsx) | 1 | Chassis |

| | |
|---|---|
| Components subtotal | **R 1 676.00** |
| Contingency (10 %) | R 167.60 |
| **Total cost of implementation** | **R 1 843.60** |

Prices are indicative South African retail. The yellow cells in the spreadsheet
are the ones to confirm against each supplier's live listing before submission.

---

## 4. Mechanical design

*Full detail: [`../Folder B/Mechanical Design/MECHANICAL_DESIGN.md`](../Folder%20B/Mechanical%20Design/MECHANICAL_DESIGN.md)*

Assembled chassis

### 4.1 Fabrication

**The deck is laser cut, not drilled.**
`Folder B/Mechanical Design/CAD/deck_plate_laser_cut.dxf` is a 1:1 flat profile
containing the outline, all 34 M3 clearance holes, the 22.5 mm E-Stop bore, the
lightening holes and the two cable slots. It goes to the cutter as-is. Nothing
is marked out by hand, because hand-drilled acrylic chips and hand-marked
patterns do not repeat.

We chose a laser-cut flat deck over a 3D-printed monocoque deliberately. A
printed 300 mm chassis warps, takes eight hours, and cannot be re-cut in an
afternoon when a mounting hole turns out to be 4 mm out. A flat plate takes
ninety seconds on the machine and is dimensionally exact. In a competition where
the schedule is the real constraint, that beats the better-looking option.

3 mm rather than 5 mm: 3 mm cast acrylic spanning 300 mm deflects about 0.4 mm
at the nose under the assembled mass — well inside the ±2 mm the sensor ride
height tolerates. 5 mm would add 240 g for stiffness we do not need.

The E-Stop mast is the only 3D-printed part: 30 mm diameter × 48 mm, four
perimeters, 40 % infill, PLA.

### 4.2 Fastening

Exploded assembly

**Every joint is bolted. Nothing is glued.** Adhesive joints in acrylic are
brittle, cannot be adjusted, and leave no way back when a sensor turns out to be
2 mm too low. Bolted joints come apart.

Motors bolt through the deck from below on two M3 per side. The castor bolts to
a 24 mm square M3 pattern at the tail. The sensor boom hangs on two M3 × 30 mm
**nylon** standoffs — nylon and not steel, because the standoffs sit directly
beside the IR emitters and a steel post reflects. Deck modules sit on 8 mm
standoffs. The battery pack is strapped with hook-and-loop so a flat pack is a
ten-second swap between heats.

Two adjustments are designed in on purpose: **sensor ride height** (change the
standoff length) and **weight distribution** (move the battery straps). Motor
position is deliberately fixed, because it sets the sensor lead that the speed
schedule depends on.

### 4.3 Views

Orthographic views

Underside

The model is parametric — a Python script using CadQuery on the OpenCASCADE
kernel. Changing `TRACK` or `WHEEL_D` and re-running regenerates every STEP,
every STL, the DXF and all five renders consistently.

---

## 5. Electronic design

*Full detail: [`../Folder B/Electronic Design/ELECTRONIC_DESIGN.md`](../Folder%20B/Electronic%20Design/ELECTRONIC_DESIGN.md)
and [`../Folder B/Schematics/SCHEMATICS.md`](../Folder%20B/Schematics/SCHEMATICS.md)*

### 5.1 The safety chain — Constraints 3 and 4

Power and safety chain

```
BT1/BT2  →  F1  →  SW1 (E-STOP)  →  SW2 (ON/OFF)  →  U1 (L298N)  →  motors
2 × 9 V     2 A     latching NC       SPST rocker      +12V           M1, M2
                                                          ↓
                                                   78M05 → +5 V rail
                                                          ↓
                                              Arduino Uno · TCRT5000 array
```

**SW1 — Emergency Stop.** A 22 mm latching mushroom head, normally closed, on a
48 mm mast at the rear centreline. It is the tallest object on the car and
nothing overhangs it, so it can be struck from above or behind with an open palm
while the car is moving. It is the **first device in the battery positive line**,
upstream of SW2 and of the H-bridge.

Three properties make it a real emergency stop rather than a decorative one:

1. **Everything is downstream.** The L298N's on-board 78M05 derives the 5 V
   logic rail from the same switched line that feeds the motors, so opening SW1
   de-energises the motors, the H-bridge, the regulator, the MCU and the sensor
   array in the same instant.
2. **Firmware cannot defeat it.** The contact is mechanically in series with the
   battery. There is no software left running once it opens.
3. **Stored energy cannot move the car.** The largest capacitor downstream is
   100 µF on the 5 V rail, storing 1.25 mJ. Turning a loaded TT gearbox through
   one revolution needs on the order of a joule — roughly a thousand times more.

This is also why we deliberately do **not** run a separate logic battery. A
second supply would keep the MCU alive after the motor rail opened, which is
exactly what Constraint 4 is written to prevent.

**SW2 — ON/OFF.** An SPST rocker at the rear-left corner of the deck, clear of
the wheels and the sensor boom, operable with the car on the grid. Both devices
are at the rear because that is the end an operator approaches from; the E-Stop
is raised and on the centreline, the rocker is flush and in the corner, so they
are not confusable by feel.

Safety hardware annotated

### 5.2 Full system wiring

Full system schematic

### 5.3 Component justification, in brief

**Arduino Uno R3.** Six ADC channels, three timers, a 104 µs ADC conversion. The
whole control pipeline measures ~760 µs against a 5 ms period — 15 % CPU. We
seriously considered an ESP32 and rejected it for one decisive reason: it
arrives with Wi-Fi and Bluetooth radios on the die, and Robo Grand Prix forbids
remote control. We would rather hand a judge a board that *physically cannot* be
commanded remotely than a board where the argument depends on firmware we claim
we did not write.

**L298N.** 2 A per channel against a ~1.2 A stall, with flyback diodes and the
5 V regulator already on the module — which removes a hand-wired subcircuit from
a breadboard, and a hand-wired flyback diode on a breadboard is exactly what goes
intermittent. Its honest downside is a ~1.9 V bridge drop, so the wheels do not
turn below about 16 % duty; `PWM_DEADBAND` in the firmware maps the controller's
output onto the usable duty range, and the calibration sketch measures the real
figure. A TB6612FNG would be the better part and is a drop-in swap if one is in
hand; the L298N was chosen on availability and cost.

**Five analog sensor channels, not three digital ones.** This is the most
consequential electronic decision on the car, and it came directly out of
simulation — see §7.

**Pin map detail that matters.** The motor PWM pins are on **Timer1 (D9, D10)**,
not Timer0 (D5, D6). Timer0 drives `millis()`/`micros()`, which the fixed-rate
scheduler depends on. Sharing it with motor PWM is the kind of coupling that
produces a bug you only see at one duty cycle, three days before the event.

**Grounding.** Single star point at the L298N GND pad. The sensor array, the Uno
and the H-bridge each return there independently rather than daisy-chaining, so
motor current never shares a conductor with the analog sensor return.

---

## 6. Programming and framework design

*Full detail: [`../Folder A/PROGRAMMING.md`](../Folder%20A/PROGRAMMING.md)*

### 6.1 Architecture

A non-blocking fixed-rate **200 Hz superloop** with a four-stage pipeline, under
a five-state supervisor. No RTOS, no dynamic allocation, no `String`, no
`delay()` anywhere in the race path.

System architecture

Main control loop

### 6.2 The control law

**Steering in curvature, not in PWM difference.** The naive line follower adds
its error to one motor's PWM and subtracts it from the other. The gain that
feels right at low speed oversteers at high speed, because the same PWM
difference produces a much tighter turn when the car is moving slowly. You end
up tuning one set of gains per speed.

Our PID instead outputs a **path curvature** κ in 1/m. For wheel separation *b*:

```
v_left  = v · (1 − κ·b/2)
v_right = v · (1 + κ·b/2)
```

κ = 5 1/m is a 200 mm radius turn at 0.2 m/s and a 200 mm radius turn at
0.5 m/s. One set of gains, every speed.

**The error is a distance, in metres**, from a weighted centroid over five
per-channel-normalised analog readings — not a unitless index. That is what lets
the gains be reasoned about geometrically: `K_P = 34` means a 20 mm offset asks
for roughly a 1.5 m radius.

**The speed schedule is where the time is won:**

```
v_wheel = V_MAX / (1 + |κ|·b/2)          # the outer wheel saturates here
v_curve = V_STRAIGHT / (1 + 0.075·|κ|)   # grip and tracking-margin limit
v       = max(V_FLOOR, min(V_STRAIGHT, v_wheel, v_curve))
```

`v_wheel` is arithmetic, not a tuned number: at curvature κ the outer wheel must
run at `v·(1 + κ·b/2)`, so any faster and the wheel is clipped, the actual
curvature is lower than commanded, and the car runs wide on exactly the corner
where it mattered. Speed is picked from the curvature the controller is *about
to* demand — and the sensor bar's 138 mm lead gives the car the distance in
which to shed that speed.

**On saturation, both wheels are scaled by the same factor.** This preserves the
ratio between them and therefore the path curvature: the car takes the corner it
asked for, just slower. Clamping only the fast wheel changes the radius and runs
the car wide — the classic way a fast line follower loses a corner.

### 6.3 States and failure

State machine

Motors are commanded off in `setup()` before anything else runs, so a brown-out
reset cannot leave a wheel driven. The **E-Stop is deliberately not a state** —
it removes power from the MCU, so modelling it in firmware would imply software
could observe or override it. `ST_FAULT` latches; a car that lost the line and
stopped does not restart itself.

Line loss recovery

On line loss the car **always continues forward and never reverses**, for two
reasons: the sensor bar leads the axle by 138 mm, so continuing the arc sweeps
the bar back over where the line geometrically is; and reversing on a shared
track is how you cause a collision with the car behind you. After 2500 ms it
stops and latches — a stationary car is a hazard a marshal can deal with, a car
searching at speed is not.

### 6.4 Category alignment

No radio, no Wi-Fi, no Bluetooth, no serial command path — `Serial` is written
to and never read. One human input, the ARM button, pressed before the car is
released. There is no weapon code, no combat logic, no teleoperation and nothing
borrowed from another category.

---

## 7. Simulation

*Full detail: [`../Folder B/Simulation/SIMULATION.md`](../Folder%20B/Simulation/SIMULATION.md)*

The control law was developed in **Webots** on an e-puck differential-drive
model before any hardware existed, because the interesting question — *how fast
can the car enter a corner and still come out on the line* — costs sensors,
tyres and afternoons to answer on real hardware.

Three findings changed the design:

1. **The outer wheel saturates before grip runs out.** On the simulated circuit
   the car could do 0.129 m/s flat out but only 0.096 m/s through the tightest
   corner before the outer wheel hit its limit. Measured lap times matched that
   prediction. This produced the `v_wheel` ceiling.
2. **Scale both wheels, never clamp one.** Four lines of code, and it was worth
   the whole exercise.
3. **Discrete sensing is what limits the derivative term.** The e-puck's three
   *binary* sensors quantise the error to five values, so every change is a step
   and differentiating it produces an impulse — which is why the simulation had
   to filter most of the derivative's usefulness away. **This is why Lightning
   McQueen carries five analog channels rather than three digital ones.** A
   weighted centroid is continuous, so the derivative term is genuinely usable.

What simulation did **not** tell us, stated plainly: there is no tyre friction
model, no sensor noise or ambient light, no H-bridge deadband, no battery sag,
and the e-puck is not our vehicle. Every scaled constant is a prediction to be
verified on the real car, and `calibration.ino` exists precisely to do that
verification.

---

## 8. Build status and next steps

| | |
|---|---|
| Control law | Developed and swept in Webots ✔ |
| Firmware | Written, commented, pin map fixed ✔ |
| CAD | Parametric model complete; STEP, STL and laser-cut DXF exported ✔ |
| Schematics | Complete, with both safety devices annotated ✔ |
| BOM | Costed at R 1 843.60 ✔ |
| Physical build | Documented, not yet assembled |

**Next, in order:** cut the deck from the DXF · assemble and loom · run
`calibration.ino` on the competition track surface · sweep `CORNER_SLOW` on the
physical car and compare against the simulation prediction · time laps.

---

## 9. Credits and attribution

- The Webots control law began from the standard e-puck line-following example
  distributed with Webots, and was rewritten around curvature control and a
  speed schedule. The original example's structure is acknowledged.
- TCRT5000 mounting follows the device datasheet's recommended 8–15 mm standoff.
- Everything else — the firmware, the CAD, the schematics and this
  documentation — is our own work.

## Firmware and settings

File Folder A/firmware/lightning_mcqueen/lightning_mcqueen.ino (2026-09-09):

/* =====================================================================
 * Lightning McQueen  -  autonomous line-following racer
 * Team CO Coders  |  Robo Rumble 2026  |  Robo Grand Prix
 * ---------------------------------------------------------------------
 * Target : Arduino Uno R3 + L298N dual H-bridge + 2 x TT gear motor
 * Sensing: 5-channel TCRT5000 reflective array, 20 mm pitch
 *
 * CATEGORY COMPLIANCE
 *   Robo Grand Prix requires the robot to be fully autonomous. There is
 *   no radio, no Wi-Fi, no Bluetooth and no serial command path in this
 *   firmware. The only human input is a momentary ARM button pressed
 *   before the run starts, and the hardware E-Stop, which cuts battery
 *   positive and is therefore invisible to software by design.
 *
 * CONTROL ARCHITECTURE
 *   A non-blocking fixed-rate (200 Hz) superloop running a four-stage
 *   pipeline, plus a five-state supervisory machine:
 *
 *     SENSE  -> read 5 ADCs, normalise against calibration
 *     FUSE   -> weighted centroid gives a cross-track error in metres
 *     PLAN   -> PID on that error outputs a PATH CURVATURE (1/m), then
 *               a speed schedule picks the fastest speed that curvature
 *               allows before the outer wheel saturates
 *     ACT    -> differential-drive kinematics turns (v, kappa) into two
 *               wheel speeds, slew-limited, deadband-compensated, PWM
 *
 *   Steering in curvature rather than in "PWM difference" is the tweak
 *   that carries over from our Webots work: the same gains behave the
 *   same way at every speed, because curvature is a property of the
 *   path, not of the throttle.
 *
 * See ../../PROGRAMMING.md for the flowcharts and the derivation.
 * ===================================================================== */

#include "config.h"

/* ------------------------------------------------------------------ */
/* Supervisory states                                                  */
/* ------------------------------------------------------------------ */
enum State {
  ST_BOOT,      // power-up self-test
  ST_DISARMED,  // waiting for the ARM button, motors electrically idle
  ST_ARMED,     // armed, 3 s countdown, still not moving
  ST_RACING,    // closed-loop line following
  ST_FAULT      // line lost too long, or self-test failed: motors off
};

static State state = ST_BOOT;

/* Controller memory ------------------------------------------------- */
static float integral      = 0.0f;
static float prevError     = 0.0f;
static float filteredD     = 0.0f;
static float lastKappa     = 0.0f;
static float vCmd          = 0.0f;
static float kappaCmd      = 0.0f;
static bool  firstStep     = true;

/* Timing ------------------------------------------------------------ */
static uint32_t lastControlUs = 0;
static uint32_t lastTelemMs   = 0;
static uint32_t stateEnteredMs = 0;
static uint32_t lostMs        = 0;

/* Telemetry --------------------------------------------------------- */
static float distanceM = 0.0f;
static float vPeak     = 0.0f;
static uint32_t lapMs  = 0;

/* ------------------------------------------------------------------ */
/* Small helpers                                                       */
/* ------------------------------------------------------------------ */
static inline float clampf(float v, float lo, float hi) {
  return v < lo ? lo : (v > hi ? hi : v);
}

/* Move `current` toward `target` no faster than maxRate per second. */
static inline float slew(float target, float current, float maxRate, float dt) {
  const float lim = maxRate * dt;
  return current + clampf(target - current, -lim, lim);
}

static void enterState(State s) {
  state = s;
  stateEnteredMs = millis();
}

/* ------------------------------------------------------------------ */
/* SENSE + FUSE                                                        */
/* ------------------------------------------------------------------ */
/* Returns true when the line is visible. On true, *errorM holds the
 * cross-track error in metres: positive means the line is to the RIGHT
 * of the vehicle centreline, so the car must steer right.
 *
 * A weighted centroid is used rather than the discrete (a - b) / total
 * of the Webots prototype. With five analog channels the centroid is
 * continuous, which removes the quantisation steps that forced the
 * simulator's derivative term to be so heavily filtered.
 */
static bool readLine(float *errorM, float *totalWeight) {
  float sumW = 0.0f;
  float sumWX = 0.0f;

  for (uint8_t i = 0; i < N_SENSORS; i++) {
    const int raw = analogRead(SENSOR_PIN[i]);

    /* Normalise this channel against its own calibration. Per-channel
     * calibration matters: the five TCRT5000s have different LED
     * brightness and different phototransistor gain. */
    float n = (float)(raw - SENSOR_MIN[i]) /
              (float)(SENSOR_MAX[i] - SENSOR_MIN[i]);
    n = clampf(n, 0.0f, 1.0f);

    /* Anything below the on-line fraction is floor, not line. Squaring
     * what remains sharpens the centroid against reflections. */
    if (n < ON_LINE_FRACTION) continue;
    const float w = (n - ON_LINE_FRACTION) / (1.0f - ON_LINE_FRACTION);
    const float w2 = w * w;

    sumW  += w2;
    sumWX += w2 * SENSOR_OFFSET_MM[i];
  }

  *totalWeight = sumW;
  if (sumW < MIN_TOTAL_WEIGHT) return false;

  *errorM = (sumWX / sumW) / 1000.0f;   // mm -> m
  return true;
}

/* ------------------------------------------------------------------ */
/* ACT  -  differential drive, deadband compensation, PWM              */
/* ------------------------------------------------------------------ */
static void driveWheel(uint8_t inA, uint8_t inB, uint8_t en, float omega) {
  const bool forward = (omega >= 0.0f);
  float mag = fabsf(omega) / MAX_WHEEL_OMEGA;      // 0..1
  mag = clampf(mag, 0.0f, 1.0f);

  int pwm = 0;
  if (mag > 0.002f) {
    /* Map 0..1 onto DEADBAND..255 so a small command still turns the
     * wheel instead of only heating the H-bridge. */
    pwm = PWM_DEADBAND + (int)(mag * (255.0f - PWM_DEADBAND));
    pwm = constrain(pwm, 0, 255);
  }

  digitalWrite(inA, forward ? HIGH : LOW);
  digitalWrite(inB, forward ? LOW  : HIGH);
  analogWrite(en, pwm);
}

static void coast() {
  analogWrite(PIN_ENA, 0);
  analogWrite(PIN_ENB, 0);
  digitalWrite(PIN_IN1, LOW); digitalWrite(PIN_IN2, LOW);
  digitalWrite(PIN_IN3, LOW); digitalWrite(PIN_IN4, LOW);
  vCmd = 0.0f;
  kappaCmd = 0.0f;
}

/* Convert a body command (v m/s, kappa 1/m) into two wheel speeds.
 *   v_left  = v (1 - kappa * b / 2)
 *   v_right = v (1 + kappa * b / 2)
 * If either wheel saturates, BOTH are scaled by the same factor. That
 * preserves the path curvature and sacrifices only speed - the car
 * still takes the corner, just slower. Clamping one wheel alone would
 * change the radius and run us wide. */
static void applyBodyCommand(float v, float kappa) {
  const float half = kappa * AXLE_LENGTH_M / 2.0f;
  float vl = v * (1.0f - half);
  float vr = v * (1.0f + half);

  float wl = vl / WHEEL_RADIUS_M;
  float wr = vr / WHEEL_RADIUS_M;

  const float peak = fmaxf(fabsf(wl), fabsf(wr));
  if (peak > MAX_WHEEL_OMEGA) {
    const float s = MAX_WHEEL_OMEGA / peak;
    wl *= s;
    wr *= s;
  }

  driveWheel(PIN_IN1, PIN_IN2, PIN_ENA, wl * TRIM_LEFT);
  driveWheel(PIN_IN3, PIN_IN4, PIN_ENB, wr * TRIM_RIGHT);

  const float vActual = (wl + wr) * 0.5f * WHEEL_RADIUS_M;
  distanceM += vActual * (CONTROL_PERIOD_MS / 1000.0f);
  if (vActual > vPeak) vPeak = vActual;
}

/* ------------------------------------------------------------------ */
/* PLAN  -  one control step                                           */
/* ------------------------------------------------------------------ */
static void controlStep(float dt) {
  float errorM = 0.0f, weight = 0.0f;
  const bool seen = readLine(&errorM, &weight);

  float vTarget, kappaTarget;

  if (seen) {
    lostMs = 0;

    if (firstStep) { prevError = errorM; firstStep = false; }

    /* Derivative on a low-pass filter: the ADC noise floor is a couple
     * of LSB and raw differentiation would amplify it straight into
     * the motors. */
    const float rawD = (errorM - prevError) / dt;
    filteredD = D_ALPHA * rawD + (1.0f - D_ALPHA) * filteredD;

    /* Integral only accumulates while we are actually tracking, and is
     * clamped, so a long corner cannot wind it up into an overshoot on
     * the following straight. */
    integral = clampf(integral + errorM * dt, -I_CLAMP, I_CLAMP);
    prevError = errorM;

    kappaTarget = K_P * errorM + K_I * integral + K_D * filteredD;
    kappaTarget = clampf(kappaTarget, -KAPPA_MAX, KAPPA_MAX);
    lastKappa = kappaTarget;

    /* Speed schedule. Two independent ceilings, take the lower:
     *   vWheelLimit - the speed at which the OUTER wheel would hit its
     *                 own maximum at this curvature
     *   vCurve      - a comfort limit that trades speed for grip and
     *                 tracking margin as the corner tightens          */
    const float vWheelLimit =
        V_MAX / (1.0f + fabsf(kappaTarget) * AXLE_LENGTH_M / 2.0f);
    const float vCurve =
        V_STRAIGHT / (1.0f + CORNER_SLOW * fabsf(kappaTarget));

    vTarget = fminf(V_STRAIGHT, fminf(vWheelLimit, vCurve));
    if (vTarget < V_FLOOR) vTarget = V_FLOOR;

  } else {
    /* Line lost. Keep going forward on the last curvature - the car is
     * almost always mid-corner when this happens, so continuing the arc
     * sweeps the sensor bar back over the line. Never reverse: reversing
     * on a track with other traffic is how you cause a collision. */
    lostMs += (uint32_t)(dt * 1000.0f);

    if (lostMs > STOP_TIMEOUT_MS) {
      enterState(ST_FAULT);
      return;
    }

    kappaTarget = clampf(lastKappa, -RECOVER_KAPPA, RECOVER_KAPPA);
    vTarget = (lostMs > LOST_TIMEOUT_MS) ? RECOVER_SPEED * 0.5f
                                         : RECOVER_SPEED;
    integral = 0.0f;   // do not integrate blind
  }

  kappaCmd = slew(kappaTarget, kappaCmd, MAX_KAPPA_RATE, dt);
  vCmd     = slew(vTarget,     vCmd,     MAX_LIN_ACCEL,  dt);

  applyBodyCommand(vCmd, kappaCmd);
}

/* ------------------------------------------------------------------ */
/* Self-test                                                           */
/* ------------------------------------------------------------------ */
/* Confirms every ADC channel is alive and inside a sane band. A channel
 * reading rail-to-rail or dead flat means a disconnected sensor, and we
 * would rather find that in the pit than on the grid. */
static bool selfTest() {
  bool ok = true;
  for (uint8_t i = 0; i < N_SENSORS; i++) {
    const int raw = analogRead(SENSOR_PIN[i]);
    if (raw < 8 || raw > 1015) {
      Serial.print(F("SELFTEST FAIL: channel "));
      Serial.print(i);
      Serial.print(F(" reads "));
      Serial.println(raw);
      ok = false;
    }
  }
  return ok;
}

static void beep(uint16_t f, uint16_t ms) {
  tone(PIN_BUZZER, f, ms);
  delay(ms);
  noTone(PIN_BUZZER);
}

/* ------------------------------------------------------------------ */
/* setup / loop                                                        */
/* ------------------------------------------------------------------ */
void setup() {
  Serial.begin(115200);

  pinMode(PIN_IN1, OUTPUT); pinMode(PIN_IN2, OUTPUT); pinMode(PIN_ENA, OUTPUT);
  pinMode(PIN_IN3, OUTPUT); pinMode(PIN_IN4, OUTPUT); pinMode(PIN_ENB, OUTPUT);
  pinMode(PIN_LED, OUTPUT);
  pinMode(PIN_BUZZER, OUTPUT);
  pinMode(PIN_START, INPUT_PULLUP);

  coast();   /* motors are commanded off BEFORE anything else runs */

  Serial.println(F("Lightning McQueen | CO Coders | Robo Grand Prix 2026"));
  Serial.print(F("v_max ")); Serial.print(V_MAX, 2);
  Serial.print(F(" m/s | kappa_max ")); Serial.print(KAPPA_MAX, 1);
  Serial.print(F(" 1/m | min radius "));
  Serial.print(1000.0f / KAPPA_MAX, 0); Serial.println(F(" mm"));

  enterState(ST_BOOT);
}

void loop() {
  const uint32_t nowUs = micros();
  const uint32_t nowMs = millis();

  /* Fixed-rate scheduler. Everything below runs exactly once per
   * CONTROL_PERIOD_MS; nothing in the pipeline blocks. */
  if ((uint32_t)(nowUs - lastControlUs) < (uint32_t)CONTROL_PERIOD_MS * 1000UL)
    return;
  const float dt = (nowUs - lastControlUs) / 1000000.0f;
  lastControlUs = nowUs;

  const bool startPressed = (digitalRead(PIN_START) == LOW);

  switch (state) {

    case ST_BOOT:
      if (selfTest()) {
        beep(1800, 60);
        Serial.println(F("self-test OK - press ARM"));
        enterState(ST_DISARMED);
      } else {
        enterState(ST_FAULT);
      }
      break;

    case ST_DISARMED:
      coast();
      digitalWrite(PIN_LED, (nowMs / 500) % 2);   // slow blink
      if (startPressed) {
        beep(1200, 80);
        Serial.println(F("ARMED - 3 s"));
        enterState(ST_ARMED);
      }
      break;

    case ST_ARMED: {
      coast();
      const uint32_t held = nowMs - stateEnteredMs;
      digitalWrite(PIN_LED, (nowMs / 150) % 2);   // fast blink
      if (held >= 3000) {
        /* Reset the controller so the run starts from a clean state. */
        integral = 0; prevError = 0; filteredD = 0; lastKappa = 0;
        vCmd = 0; kappaCmd = 0; firstStep = true;
        lostMs = 0; distanceM = 0; vPeak = 0;
        lapMs = nowMs;
        beep(2200, 120);
        Serial.println(F("GO"));
        enterState(ST_RACING);
      }
      break;
    }

    case ST_RACING:
      digitalWrite(PIN_LED, HIGH);
      controlStep(dt);
      /* A press of the ARM button during a run is a soft abort. It is a
       * convenience for testing only - the hardware E-Stop is the
       * mechanism that satisfies the competition rule. */
      if (startPressed) {
        Serial.println(F("soft abort"));
        coast();
        enterState(ST_DISARMED);
      }
      break;

    case ST_FAULT:
      coast();
      digitalWrite(PIN_LED, (nowMs / 100) % 2);   // urgent blink
      if (startPressed) {
        lostMs = 0;
        enterState(ST_DISARMED);
      }
      break;
  }

  /* Telemetry. Serial is output-only - nothing is ever read from it, so
   * it cannot become a control channel. */
  if (nowMs - lastTelemMs >= TELEMETRY_PERIOD_MS) {
    lastTelemMs = nowMs;
    const float radius = (fabsf(kappaCmd) > 1e-4f) ? 1.0f / fabsf(kappaCmd)
                                                   : 0.0f;
    Serial.print(F("st ")); Serial.print((int)state);
    Serial.print(F(" | v ")); Serial.print(vCmd, 2);
    Serial.print(F(" m/s | k ")); Serial.print(kappaCmd, 2);
    Serial.print(F(" 1/m | R ")); Serial.print(radius * 1000.0f, 0);
    Serial.print(F(" mm | d ")); Serial.print(distanceM, 2);
    Serial.print(F(" m | peak ")); Serial.println(vPeak, 2);
  }
}

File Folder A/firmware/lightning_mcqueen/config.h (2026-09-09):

/* =====================================================================
 * Lightning McQueen  -  Team CO Coders
 * Robo Rumble 2026  |  Robo Grand Prix (autonomous racing)
 * ---------------------------------------------------------------------
 * config.h - every tunable in one place.
 *
 * Nothing in this file is a magic number: each constant either comes
 * from a datasheet, from the vehicle geometry in
 * Folder B/Mechanical Design/CAD/lightning_mcqueen_cad.py, or from the
 * Webots sweep documented in Folder B/Simulation/SIMULATION.md.
 * ===================================================================== */

#ifndef CONFIG_H
#define CONFIG_H

/* ------------------------------------------------------------------
 * PIN MAP  -  Arduino Uno R3
 * ------------------------------------------------------------------
 * ENA/ENB are on Timer1 (pins 9, 10) deliberately: Timer0 drives
 * millis()/micros() on pins 5 and 6, and we would rather not share it.
 */
#define PIN_IN1        2      // L298N IN1  - left motor direction A
#define PIN_IN2        4      // L298N IN2  - left motor direction B
#define PIN_ENA        9      // L298N ENA  - left motor PWM   (Timer1)
#define PIN_IN3        7      // L298N IN3  - right motor direction A
#define PIN_IN4        8      // L298N IN4  - right motor direction B
#define PIN_ENB       10      // L298N ENB  - right motor PWM  (Timer1)

#define PIN_START     12      // momentary arm/start button, INPUT_PULLUP
#define PIN_LED       13      // on-board LED, doubles as the status light
#define PIN_BUZZER     3      // piezo, audible arm/disarm and fault codes

/* 5-channel TCRT5000 array, left-to-right when looking forward. */
#define N_SENSORS      5
static const uint8_t SENSOR_PIN[N_SENSORS] = { A0, A1, A2, A3, A4 };

/* Sensor lateral offsets in millimetres from the vehicle centreline.
 * 20 mm pitch, matching SENSOR_PITCH in the CAD model. Used to turn the
 * raw readings into a physical cross-track error rather than a unitless
 * one, so the gains below have real units. */
static const float SENSOR_OFFSET_MM[N_SENSORS] = { -40, -20, 0, +20, +40 };

/* ------------------------------------------------------------------
 * VEHICLE GEOMETRY  -  mirrors the CAD model exactly
 * ------------------------------------------------------------------ */
#define WHEEL_RADIUS_M   0.0325f   // 65 mm wheel
#define AXLE_LENGTH_M    0.170f    // TRACK in the CAD model
#define SENSOR_LEAD_M    0.138f    // sensor bar ahead of the drive axle

/* TT motor, 1:48, on 9 V: ~200 rpm no-load. Derated to a realistic
 * loaded figure measured on the bench. */
#define MAX_WHEEL_RPM    170.0f
#define MAX_WHEEL_OMEGA  (MAX_WHEEL_RPM * 2.0f * 3.14159265f / 60.0f)
#define V_MAX            (WHEEL_RADIUS_M * MAX_WHEEL_OMEGA)  // ~0.58 m/s

/* ------------------------------------------------------------------
 * SPEED POLICY  (m/s)
 * ------------------------------------------------------------------
 * Same shape as the Webots controller: pick a curvature first, then
 * pick the fastest speed that curvature allows before the outer wheel
 * saturates, then clamp to a straight-line ceiling.
 */
#define V_STRAIGHT       0.52f    // straight-line target
#define V_FLOOR          0.16f    // never crawl slower than this
#define CORNER_SLOW      0.075f   // how hard curvature brakes us

/* ------------------------------------------------------------------
 * STEERING  -  PID on cross-track error, output is path curvature (1/m)
 * ------------------------------------------------------------------
 * Error is in metres. K_P = 34 means a 20 mm offset asks for
 * 0.68 1/m, a 1.47 m radius - a gentle correction, not a lurch.
 */
#define K_P              34.0f
#define K_I              0.35f
#define K_D              1.30f
#define KAPPA_MAX        14.0f    // 1/m, ~71 mm minimum radius
#define D_ALPHA          0.30f    // derivative low-pass, 0..1
#define I_CLAMP          1.50f    // anti-windup on the integral term

/* ------------------------------------------------------------------
 * RATE LIMITS
 * ------------------------------------------------------------------
 * The L298N can slam from 0 to full in one control period. These limits
 * exist so the commanded path stays smooth across the discrete sensor
 * states - they are not there to fake a weak motor.
 */
#define MAX_LIN_ACCEL    2.20f    // m/s^2
#define MAX_KAPPA_RATE   90.0f    // (1/m) per second

/* ------------------------------------------------------------------
 * LINE LOSS AND RECOVERY
 * ------------------------------------------------------------------ */
#define RECOVER_SPEED    0.20f    // m/s, always forward - never reverse
#define RECOVER_KAPPA    7.0f     // 1/m, ~143 mm radius sweep
#define LOST_TIMEOUT_MS  1200     // hold the last curvature this long
#define STOP_TIMEOUT_MS  2500     // then stop and latch a fault
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

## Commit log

2026-09-09 Refine labels in system architecture flowchart
2026-09-09 Refactor flowchart labels for clarity
2026-09-09 Refactor flowchart in 04_line_loss_recovery.mmd
2026-09-09 Refactor flowchart for line loss recovery
2026-09-09 Update flowchart labels for clarity
2026-09-09 Update CAD models and documentation
    - Modified the timestamp in the STEP file for tyre_right.step and lightning_mcqueen_assembly.step.
    - Updated multiple STL files (base_plate.stl, breadboard.stl, castor.stl, estop_head.stl, estop_mast.stl, motor_left.stl, motor_right.stl, rim_left.stl, rim_right.stl, sensor_standoffs.stl, tyre_left.stl, tyre_right.stl) to reflect binary differences.
    - Deleted the FQA_Attendance_Log.md file as it is no longer needed.
    - Updated the Pitch_Deck.pdf with formatting improvements and corrected text for clarity.
    - Adjusted cost breakdown in the Pitch Deck for better readability.
    [Bill_of_Materials.xlsx, arduino_uno.step, base_plate.step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]
